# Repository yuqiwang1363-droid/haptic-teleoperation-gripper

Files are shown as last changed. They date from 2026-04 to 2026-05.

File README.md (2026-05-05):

# Haptic Teleoperation Gripper System

## Overview

This project presents a hardware-in-the-loop (HIL) haptic device designed for teleoperation and human-machine interaction. The system consists of a 2-DOF planar linkage for position input and a 1-DOF force-feedback gripper that enables users to perceive virtual object interactions through kinesthetic feedback.

The device captures user motion using encoders and renders force feedback via a DC motor, forming a closed-loop interaction with a virtual environment.

---

## System Architecture

* **Mechanical System**

  * 2-DOF planar linkage for end-effector positioning
  * 1-DOF gripper handle with integrated DC motor for force feedback

* **Sensing**

  * Incremental encoders (Model 3806) for joint angle measurement
  * AS5600 magnetic encoder for absolute gripper angle sensing

* **Embedded System**

  * Arduino-based real-time processing
  * Quadrature decoding and angle computation
  * Motor control for haptic rendering

* **Interface**

  * Serial communication with external simulation (e.g., PyBullet)
  * Enables hardware-in-the-loop interaction

---

## My Contributions

* Designed the **2-DOF linkage mechanism** and **force-feedback handle**
* Performed **component selection** (encoders, motor, sensors)
* Integrated **incremental encoders and AS5600 sensor**
* Developed **Arduino firmware** for sensing and motor control
* Implemented **real-time data acquisition and actuation pipeline**
* Diagnosed and resolved key issues:

  * Encoder drift due to improper mounting
  * Sensor-magnet misalignment
  * Mechanical friction and usability issues
* Optimized gripper geometry and ergonomics for improved user interaction

---

## Hardware

* 2-DOF planar linkage (custom CAD design)
* RS380 DC motor for force feedback
* AS5600 magnetic encoder (I2C)
* Model 3806 incremental encoders (quadrature)
* Bearing-supported rotating handle

See `/hardware` for CAD files, wiring diagrams, and BOM.

---

## Firmware

The Arduino firmware performs:

* Encoder signal decoding (quadrature)
* Angle computation and calibration
* Serial communication
* Motor control for force feedback

Located in:

```bash
/firmware/arduino_main/
```

---

## Control and Modeling

* Forward kinematics for 2R planar linkage
* Real-time position tracking
* Haptic rendering using a virtual wall model
* Force output based on stiffness and penetration depth

See `/control` for details.

---

## Hardware-Software Interface

The system communicates with an external simulation via serial:

**Output (Arduino → Simulation):**

* End-effector position (x, y)
* Gripper angle (α)

**Input (Simulation → Arduino):**

* Contact threshold
* Virtual stiffness

This enables real-time hardware-in-the-loop interaction.

---

## Results

* Stable position tracking after mechanical refinement
* Improved accuracy through proper encoder mounting
* Smooth and responsive force feedback
* Enhanced user interaction through ergonomic design improvements

---

## Project Structure

```bash
hardware/      # CAD, drawings, electronics
firmware/      # Arduino code
experiments/   # testing and observations
docs/          # report and figures
```

---

## Demo
click the picture
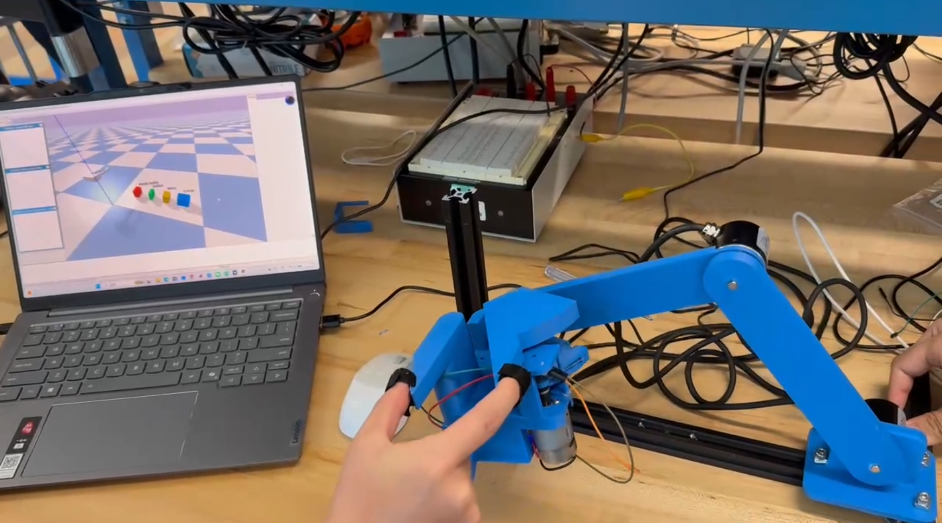
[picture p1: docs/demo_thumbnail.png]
Demo Video (https://www.bilibili.com/video/BV1hrQpB5Ezd)
 

---

## Future Work

* Improve sensing accuracy and calibration
* Reduce mechanical friction and backlash
* Enhance force feedback with advanced control strategies
* Integrate more complex virtual environments

---

## Acknowledgment
This project was conducted at the University of California, San Diego under the supervision of Professor Tania Morimoto.

## 中文说明（Chinese Version）

### 项目简介

本项目设计并实现了一种基于硬件在环（Hardware-in-the-Loop, HIL）的触觉遥操作装置。系统由一个二维平面连杆机构（2-DOF）和一个具有力反馈功能的夹爪手柄（1-DOF）组成，实现了用户动作输入与虚拟环境交互之间的闭环控制。

系统通过编码器采集用户运动信息，并利用直流电机输出力反馈，使用户能够感知虚拟物体的接触与刚度特性，从而提升人机交互的真实感。

---

### 系统结构

* **机械结构**

  * 二自由度平面连杆机构（用于末端位置输入）
  * 一自由度力反馈手柄（集成电机实现夹爪开合与力反馈）

* **传感器系统**

  * 3806 增量式编码器（用于关节角度测量）
  * AS5600 磁编码器（用于夹爪绝对角度测量）

* **嵌入式系统**

  * 基于 Arduino 的实时数据采集与控制
  * 编码器信号正交解码与角度计算
  * 电机驱动与力反馈控制

* **系统接口**

  * 通过串口与外部仿真环境（如 PyBullet）通信
  * 支持硬件在环（HIL）实时交互

---

### 本人工作内容

* 主导 **2自由度连杆机构与力反馈手柄的机械设计**
* 完成 **关键元件选型**（编码器、电机、传感器等）
* 实现 **增量式编码器与AS5600磁编码器的集成**
* 开发 **Arduino嵌入式程序**，实现数据采集与力反馈控制
* 搭建 **完整硬件系统并完成系统级集成**
* 解决关键工程问题：

  * 编码器安装不牢导致的测量误差问题
  * AS5600 磁铁与传感器对齐问题
  * 机械摩擦与结构稳定性问题
* 优化夹爪结构与人机交互设计，提高操作稳定性与触觉感知效果

---

### 硬件系统

* 2自由度平面连杆机构（自定义CAD设计）
* RS380 直流电机（用于力反馈）
* AS5600 磁编码器（I2C通信）
* 3806 增量式编码器（正交输出）
* 轴承支撑的旋转手柄结构

详细硬件设计（包括CAD模型、接线图与物料清单）详见 `/hardware` 目录。

---

### 嵌入式程序

Arduino程序实现以下功能：

* 编码器信号解码（正交解码）
* 角度计算与零位标定
* 串口通信（与上位机/仿真环境交互）
* 电机驱动与力反馈控制

程序代码详见 `/firmware/arduino_main/` 目录。

---

### 控制与建模

* 基于平面2R机构的正运动学进行末端位置计算
* 实现实时位置跟踪与数据映射
* 基于虚拟墙模型（Virtual Wall）实现力反馈
* 根据接触阈值与刚度参数输出反馈力

相关建模与控制细节详见 `/control` 目录。

---

### 硬件-软件接口

系统通过串口实现与外部仿真环境的数据交互：

**输出（Arduino → 仿真）：**

* 末端位置 (x, y)
* 夹爪角度 (α)

**输入（仿真 → Arduino）：**

* 接触阈值（contact threshold）
* 虚拟刚度参数（stiffness）

该机制实现了物理设备与虚拟环境之间的闭环交互（Hardware-in-the-Loop）。

---

### 实验结果

* 通过机械结构优化，实现稳定的位置跟踪
* 编码器固定后显著降低零点漂移与测量误差
* 力反馈输出平滑且响应稳定
* 结构优化后显著提升用户操作体验与交互自然性

实验数据与调试记录详见 `/experiments` 目录。

---

### 项目结构

```bash
hardware/      # 机械设计、CAD模型与电路连接
firmware/      # Arduino嵌入式控制代码
experiments/   # 测试记录、标定与调试过程
docs/          # 报告、图片与说明文档
```

---

### 演示

点击照片
Demo Video (https://www.bilibili.com/video/BV1hrQpB5Ezd) 

---

### 后续工作

* 提升传感器精度与系统标定方法
* 降低机械摩擦与间隙误差（backlash）
* 优化力反馈控制算法（如更高阶控制策略）
* 扩展更复杂的虚拟交互环境

---

### 致谢

本项目在加州大学圣地亚哥分校完成，感谢 Tania Morimoto 教授的指导与支持。

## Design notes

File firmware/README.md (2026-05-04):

# Firmware / 固件

---

## Overview / 项目简介

This firmware runs on an Arduino microcontroller and implements real-time sensing, communication, and force-feedback control for the haptic device.

The system reads joint motion from incremental encoders, measures gripper rotation using an AS5600 magnetic sensor, and communicates with an external system via serial. Based on incoming commands, it drives a DC motor to render haptic feedback.

本固件运行在 Arduino 微控制器上，实现触觉设备的实时数据采集、通信以及力反馈控制。

系统通过读取连杆上的增量式编码器获取关节运动信息，通过 AS5600 磁编码器测量夹爪角度，并通过串口与外部系统（如仿真环境）通信，根据接收到的控制指令驱动电机输出力反馈。

---

## Architecture / 系统架构

Although implemented in a single `.ino` file, the firmware is logically organized into several functional modules:

尽管代码目前以单个 `.ino` 文件实现，但在逻辑上可划分为以下模块：

* **Sensing（传感层）**

  * Read joint angles from incremental encoders
  * Read gripper angle from AS5600 (I2C)

* **State Processing（状态处理）**

  * Convert encoder counts to angles
  * Maintain system state (joint angles + gripper angle)

* **Communication（通信模块）**

  * Send real-time data via serial
  * Receive control parameters from host

* **Control（控制模块）**

  * Compute force feedback command
  * Drive DC motor using PWM

---

## Main Loop / 主循环结构

The firmware follows a structured loop:

固件采用结构化循环：

```cpp
void loop() {
    readEncoders();
    readGripper();
    computeState();
    sendData();
    receiveCommand();
    controlMotor();
}
```

This structure separates sensing, processing, communication, and actuation.

该结构实现了传感、处理、通信与控制的分层设计。

---

## Hardware Interface / 硬件接口

### Incremental Encoders (Model 3806) / 增量式编码器

* Quadrature signals (A/B channels)
* Used for joint angle measurement
* High-resolution relative motion tracking

用于关节角度测量，通过A/B相实现高分辨率位置跟踪。

---

### AS5600 Magnetic Encoder / 磁编码器

* I2C communication (SDA, SCL)
* Absolute angle measurement (0–360°)

用于夹爪角度测量，提供绝对角度信息。

---

### Motor Driver / 电机驱动

* PWM output for torque control
* Direction controlled via digital pins

通过PWM控制输出力矩，实现力反馈。

---

## Serial Communication / 串口通信

### Output (Arduino → Host) / 输出

```text
< x, y, alpha >
```

* `x, y`: end-effector position
* `alpha`: gripper angle

---

### Input (Host → Arduino) / 输入

* Contact threshold
* Stiffness parameter

用于计算力反馈控制信号。

---

## Control Logic / 控制逻辑

Force feedback is implemented using a simple virtual wall model:

系统采用虚拟墙模型实现力反馈：

```cpp
float error = contact_angle - alpha;
float torque = k * error;
```

The torque is converted into a PWM signal to drive the motor.

根据误差计算力矩，并转换为PWM信号驱动电机。

---

## Key Engineering Issues / 关键工程问题

### Encoder Drift / 编码器漂移

* Issue: system failed to return to zero
* Cause: loose encoder mounting
* Fix: rigid mounting using screws

---

### AS5600 Alignment / 传感器对齐

* Issue: unstable angle readings
* Cause: magnet misalignment
* Fix: adjust alignment and maintain 1–3 mm gap

---

### Real-Time Performance / 实时性

* Continuous loop ensures real-time response
* Serial communication optimized to avoid blocking

---

## File Location / 文件位置

```bash
arduino_main/arduino_main.ino
```

---

## Future Work / 后续优化

* Refactor into modular `.h/.cpp` structure
* Implement interrupt-based encoder decoding
* Improve control strategy (e.g., impedance control)
* Add filtering for noise reduction

后续可优化为模块化结构，并引入更高级控制与滤波方法。

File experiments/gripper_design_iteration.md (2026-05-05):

# Gripper Design Iteration

---

## Overview

During early testing, the gripper design was found to limit the user's ability to perceive object size and perform stable manipulation.

This led to a redesign of the gripper geometry to improve tactile interaction and usability.

---

## Problem Description

* Users could not fully close their fingers when interacting with the gripper
* The distance between the two contact surfaces was too large
* Tactile perception of object size was poor
* Interaction felt unnatural and imprecise

This indicated that the initial design did not adequately consider human ergonomics.

---

## Root Cause Analysis

The issue was primarily caused by the geometry of the gripper:

* The front section of the gripper was too thick
* The contact region between the user's fingers and the gripper was too far apart
* The design prioritized structural simplicity over user interaction

As a result, users were unable to achieve natural pinch-like interaction.

---

## Design Modification

To address these issues, the gripper geometry was redesigned:

* The front section of the gripper was tapered (reduced thickness)
* The contact region was brought closer to allow better finger closure
* The shape was adjusted to improve ergonomic compatibility

---

## Results

After redesign:

* Users could comfortably close their fingers around the gripper
* Tactile perception of object size was significantly improved
* Interaction became more natural and controllable

---

## Engineering Insight

This iteration demonstrates that:

> Mechanical design must consider not only structural integrity, but also human interaction.

Even small geometric changes can significantly affect usability and perception.

---

---

# 夹爪结构优化

---

## 概述

在初期测试中发现，夹爪结构设计限制了用户对物体尺寸的感知能力，同时操作稳定性较差。

因此对夹爪结构进行了优化，以提升触觉交互效果与使用体验。

---

## 问题描述

* 用户无法完全闭合手指进行操作
* 两个接触面之间距离过大
* 对物体尺寸的感知能力较差
* 操作过程不自然，控制精度低

说明初始设计未充分考虑人机交互需求。

---

## 原因分析

问题主要来源于夹爪的几何结构：

* 前端结构过厚
* 手指接触区域间距较大
* 设计更偏向结构实现，而非操作体验

导致用户无法实现自然的“捏合”动作。

---

## 结构改进

针对该问题进行了如下优化：

* 对夹爪前端进行斜向减薄（tapered design）
* 缩小接触区域之间的距离
* 调整整体形状以提升人体工学适配性

---

## 改进效果

优化后：

* 用户可以自然闭合手指进行操作
* 对物体尺寸的感知明显提升
* 操作更加稳定、自然

---

## 工程启示

该改进表明：

> 机械设计不仅要满足结构需求，还需要考虑人机交互体验。

细微的结构变化也可能对系统性能产生显著影响。

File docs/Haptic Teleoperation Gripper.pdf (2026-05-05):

Abstract — Existing virtual teleoperation systems often lack adequate haptic feedback, creating a "transparency gap" that diminishes the physical realism of human demonstrations. To address this, we present a low-cost, high-fidelity haptic teleoperation gripper based on an impedance-type Hardware-in-
the-Loop | (HIL) | architecture. | The | system | seamlessly
synchronizes physical kinesthetic inputs with a PyBullet physics engine in real-time. By employing a dynamic unilateral virtual wall model, the system calculates spatial contact thresholds and modulates virtual stiffness to actuate a DC motor, generating proportional resistive torque. This allows operators to accurately perceive both the geometric size and material compliance of virtual objects. Supported by optimized signal filtering to eliminate mechanical jitter, the interface provides stable bidirectional force feedback, demonstrating significant potential for generating physically consistent data for Sim-to-Real manipulation tasks.

Keywords: Haptic Feedback, Teleoperation, Hardware-inthe-Loop, Impedance Control, Virtual Environment

I. INTRODUCTION
The | development | of | high-performance | robotic
manipulation policies increasingly relies on large-scale, high-quality demonstration datasets, especially within the Sim-to-Real paradigm. However, traditional data collection through physical robotic systems is often constrained by high hardware costs, maintenance requirements, and limited scalability. As a result, virtual environments have emerged as a promising alternative for scalable data generation. Nevertheless, existing virtual teleoperation systems frequently lack sufficient haptic feedback, leading to a significant “transparency gap” between user actions and perceived interaction forces.

In particular, when operators manipulate virtual objects without force feedback, they are unable to accurately perceive contact events or object properties such as stiffness and rigidity. This limitation often results in unrealistic demonstrations, reducing the effectiveness of collected data for training robotic policies. To address this issue, it is essential to design interfaces that provide synchronized kinesthetic feedback, enabling users to experience physically consistent interactions within simulated environments.

In this project, we present a wearable kinesthetic feedback interface designed for teleoperation of a robotic gripper in a virtual environment. The system establishes a bidirectional interaction loop: user finger motions are captured through

*Research supported by ABC Foundation.
F. A. Author is with the National Institute of Standards and Technology, Boulder, CO 80305 USA (corresponding author to provide phone: 303-555-5555; fax: 303-555-5555; e-mail: author@ boulder.nist.gov).

high-precision angle sensing and mapped to a virtual gripper, while a motorized actuation mechanism generates reverse torque proportional to simulated interaction forces. This active resistance allows users to perceive contact and grasp forces in real time, thereby improving the realism and fidelity of teleoperation.

Our design focuses on accessibility, scalability, and usability. By employing a lightweight wearable structure and a simplified two-finger interaction paradigm, the system lowers the barrier to large-scale demonstration data collection. Additionally, the integration of force feedback enhances human-in-the-loop control, making the interface suitable for generating high-quality training data for robotic learning systems.

II. BACKGROUND

Recent advances in teleoperation and haptic feedback systems have demonstrated the importance of combining motion capture with force feedback to achieve realistic and effective human–robot interaction. Vision-based teleoperation frameworks such as DexPilot [1] enable high-fidelity retargeting of human hand motions to robotic manipulators, significantly improving task performance and providing valuable demonstration data. However, these systems primarily focus on motion mapping and lack sufficient haptic feedback, limiting the operator’s ability to perceive interaction forces.

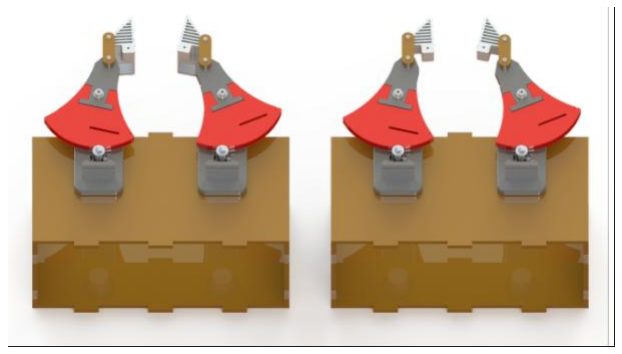
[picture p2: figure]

Figure 1 Teleoperated Two-Finger Gripper [5]

To address this limitation, various wearable haptic devices have been developed to provide kinesthetic feedback. Peng et al. [2] introduced a lightweight exoskeleton glove that employs mechanical linkages and impedance control to render grasping resistance, improving perceived realism and safety.

S. B. Author, Jr., was with Rice University, Houston, TX 77005 USA. He is now with the Department of Physics, Colorado State University, Fort Collins, CO 80523 USA (e-mail: author@lamar. colostate.edu).
T. C. Author is with the Electrical Engineering Department, University of Colorado, Boulder, CO 80309 USA, on leave from the National Research Institute for Metals, Tsukuba, Japan (e-mail: author@nrim.go.jp).

## Haptic Teleoperation Gripper

Yukang Hu, Dongjun Tan, Yuqi Wang University of California, San Diego

Similarly, Wang et al. [3] proposed a modular glove integrating triboelectric sensing with pneumatic actuation, enabling simultaneous cutaneous and kinesthetic feedback. These works highlight the importance of combining sensing and actuation to achieve closed-loop interaction in teleoperation systems.

In addition to active force-feedback devices, passive force rendering approaches have also been explored. Cassar and Saliba [4] developed a glove based on magnetorheological fluid (MRF), which modulates resistance through controllable damping rather than active actuation. Such passive systems offer inherent safety advantages while still providing perceptual cues about object properties. However, they may lack the dynamic range and responsiveness required for complex interaction scenarios.

Furthermore, prior studies on teleoperated grippers have demonstrated that even simple pinch-based interfaces can effectively convey material properties such as hardness and softness. The work in [5] shows that combining grasp sensing with force feedback enables users to distinguish between different object stiffness levels, supporting more realistic manipulation and interaction, as shown in Figure 1.

Building upon these prior works, our system focuses on a compact, wearable, and actively actuated interface that integrates motion sensing and torque-based force feedback within a virtual environment. By leveraging a simplified two-finger gripper paradigm and real-time force rendering, the proposed approach aims to balance system complexity, usability, and scalability for data-driven robotic learning applications.

III. HARDWARE DESIGN

A. Mechanical Design
The mechanical structure of the system is illustrated in Figure 1. The device consists of a 2-degree-of-freedom (2-DOF) planar linkage mechanism combined with a 1-degreeof-freedom (1-DOF) rotating handle located at the end effector. The full structure can be seen in Figure 2.

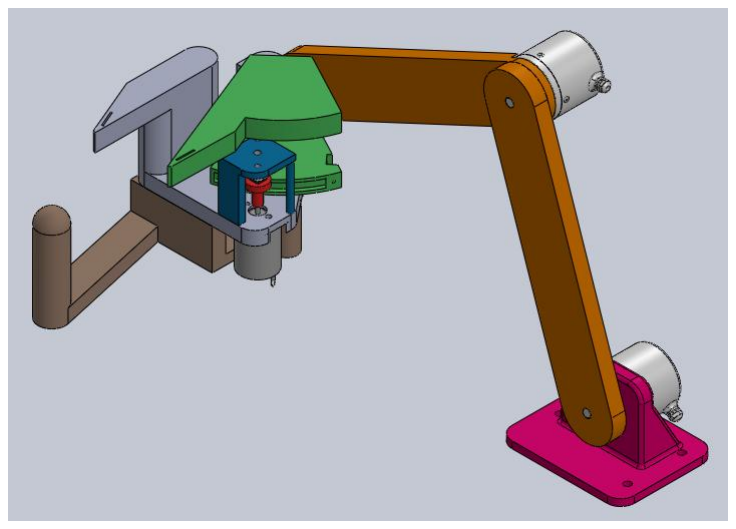
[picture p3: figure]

Figure 2 CAD model of the haptic device

The dual-linkage mechanism is responsible for enabling the planar motion of the end effector and is equipped with passive rotary joints for position sensing. This configuration allows the user to freely maneuver the handle within a two-dimensional workspace. The end-effector position is determined through forward kinematics based on the measured joint angles.

At the end effector, an additional rotational degree of freedom is introduced via a bearing-supported handle. This handle is mechanically decoupled from the linkage mechanism, allowing it to rotate independently without affecting the movement of the joints.

A DC motor is integrated within the handle to provide force feedback capabilities. A bearing connection is employed between the linkage mechanism and the handle to ensure smooth rotation while minimizing the transmission of unwanted torque to the joints.

This decoupled design enhances the human-machine interaction experience by enabling natural hand movements, while simultaneously facilitating precise position sensing through the linkage mechanism. The entire structure is designed to minimize friction and ensure the stable operation of the system.

B. Hardware Component
Regarding the hardware aspects of this system, the design incorporates passive joint sensing as well as active force feedback at the end-effector.

Two Model 3806 incremental encoders are responsible for measuring joint positions; these encoders offer high resolution for capturing relative angular data. Testing has demonstrated that they are highly suitable for tracking a user's continuous movements. Furthermore, their compact design makes them particularly convenient for mounting directly onto moving joints. As shown in Figure 3.

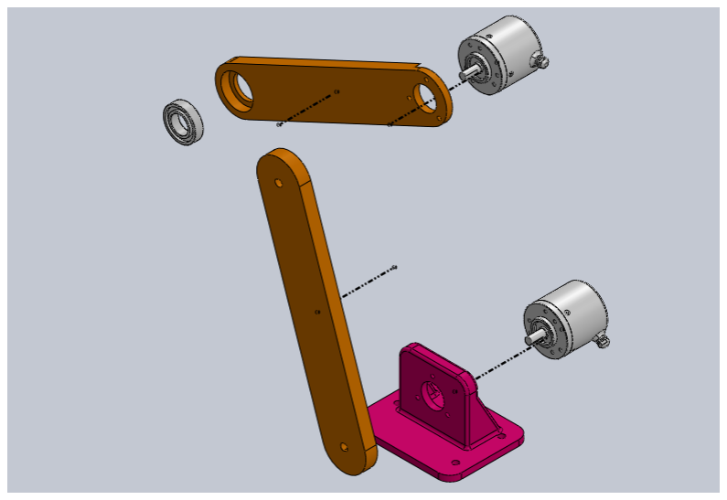
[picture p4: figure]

Figure 3 Exploded view of the linkage assembly

In the force-feedback gripper section, an AS5600 magnetic encoder is positioned atop the motor, oriented perpendicularly to the axis of rotation. As the motor rotates, a magnet mounted at the front end of the motor shaft rotates in tandem, enabling the encoder to accurately capture the motor's rotational motion. This precise monitoring ensures a stable output for the force-feedback control mechanism.

The force-feedback functionality is further realized through an RS380 DC motor mounted within the handle assembly. This motor features a compact form factor and delivers greater torque output capabilities compared to the

RS370 model utilized in the Hapkit curriculum. This design ensures effective haptic interaction while simultaneously reducing the mechanical complexity of the overall system.As shown in Figure 4.

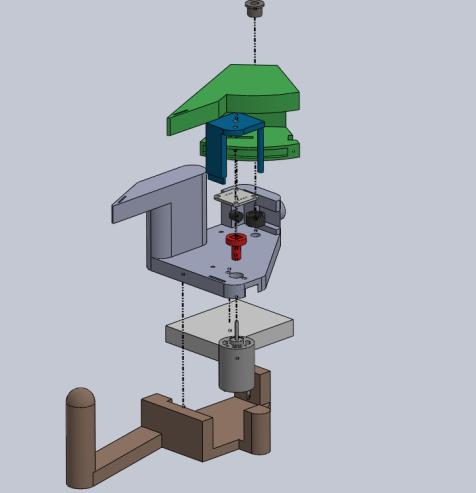
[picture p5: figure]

Figure 4 Exploded view of the end-effector handle assembly

C. Sensor Integration
The system integrates both incremental and absolute sensor technologies to ensure that information is captured in the most appropriate manner.

For the two degrees of freedom, a Model 3806 incremental encoder is installed at each joint of the linkage mechanism to measure angular displacement. Since these encoders measure changes in position rather than absolute values, the linkage must be manually set to a "zero" position, serving as the initial reference point, whenever the system is powered on.

Each encoder generates two digital signals (channels A and
B) with a 90∘phase difference, enabling both angular position tracking and rotation direction detection.

To decode the quadrature signals, a state-based lookup table is employed. At each sampling step, the current and previous states of the encoder signals are combined to form a 4-bit index, which is used to determine the incremental count update. This approach allows robust detection of valid transitions while rejecting invalid state changes due to noise.

The accumulated encoder counts are then converted into joint angles using

θ =

(c+coffset)
CPR | ⋅ 2π | (1)

where c is the accumulated count, coffset is a calibration offset corresponding to the initial configuration, and CPR denotes the counts per revolution. In our implementation, CPR is set to 2400, accounting for quadrature decoding (i.e., four counts per encoder pulse).

Additionally, a sign inversion is applied to one joint to ensure consistency with the kinematic convention of the planar 2R manipulator. Dynamics can be seen in Figure The measured joint angles are subsequently used in forward kinematics to compute the end-effector position:

x = L1 cos θ1 + L2 cos(θ1 + θ2

) | (2)

y = L1 sin θ1 + L2 sin(θ1 +θ2

) | (3)

where L1and L2 are the link lengths.

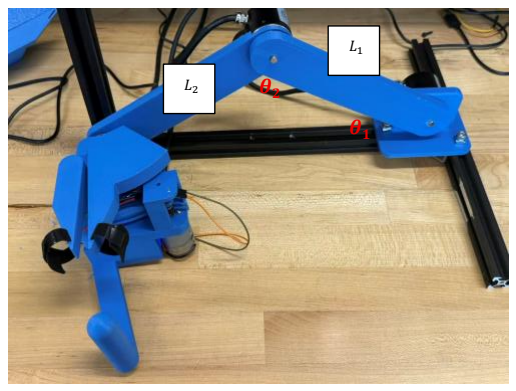
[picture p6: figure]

Figure 5 Arm Dynamics

Compared to absolute magnetic encoders, incremental encoders offer higher update rates and lower latency, making them suitable for continuous motion tracking of the linkage. However, they require initialization and are subject to cumulative drift if counts are lost. Therefore, in this system, incremental encoders are used for high-frequency joint tracking, while the absolute magnetic sensor (AS5600) is used for reliable measurement of the gripper state.

At the force-feedback handle, an AS5600 magnetic encoder is employed. This encoder provides absolute angular measurement data, thereby ensuring stable and consistent force feedback.

To measure the gripper aperture angle, a contactless magnetic rotary encoder (AS5600) is employed. The AS5600 operates based on Hall-effect sensing, where an internal array of Hall sensors detects the orientation of a diametrically magnetized permanent magnet mounted on the rotating shaft. By estimating the angular position of the magnetic field vector, the sensor provides an absolute angular measurement over a full 0

∘

to 360∘
range.

The device outputs a 12-bit digital value (0–4095), corresponding to one full revolution. The measured angle is obtained by linearly mapping the raw sensor reading to the angular domain as

θ =

N
4096 ⋅ 360∘
(4)

where Ndenotes the raw encoder value. In implementation, the sensor is accessed via the I

2C interface by reading two consecutive registers (high and low bytes), which are combined and masked to obtain the 12-bit angle measurement.

Compared to incremental encoders used for joint position sensing, the AS5600 provides absolute angle measurements without requiring initialization or homing. This property makes it particularly suitable for measuring the gripper aperture, where reliable and drift-free position sensing is essential despite cable transmission compliance or mechanical backlash.

Precise alignment between the sensors and their corresponding rotating components is critical to achieving accurate measurements. Specifically, the air gap between the AS5600 sensor and its magnet must be maintained within the recommended range of 1 to 3 millimeters. The incremental encoders, conversely, are rigidly mounted to prevent misalignment and ensure reliable signal output.

By precisely capturing the motion of every joint using these two distinct sensor technologies, the system ensures the overall robustness of the haptic interaction experience.

IV. SOFTWARE DESIGN

A. Position Mapping
The software system establishes a real-time mapping between the physical haptic device and the virtual gripper in the PyBullet environment. The Arduino continuously transmits three values through serial communication: the planar end-effector position (x, y) in centimeters and the gripper handle angle αin degrees. These measurements are parsed by the Python simulation program and converted into the pose command of a WSG50 gripper model.

Since the physical device is designed for planar motion, only two translational degrees of freedom are mapped into the virtual workspace. Specifically, the measured horizontal displacement is mapped to the PyBullet X-axis, while the measured vertical displacement of the physical linkage is mapped to the PyBullet Z-axis. The virtual gripper remains at a fixed Y-position so that the interaction is constrained to a two-dimensional manipulation plane. The mapping is defined as
Xv = kx x | (5)
Zv = kz y +Zoff | (6)
Yv = 0 | (7)

where xand yare the measured end-effector coordinates from the hardware in centimeters, Xv

, Yv | , and Zv denote the
virtual gripper position in meters, kx and kz are workspace scaling coefficients, and Zoffis a constant height offset used to keep the gripper above the virtual ground plane. In the current implementation, kx = 15/100 , kz = 5/100 , and Zoff = 0.05m. This anisotropic scaling was selected empirically to produce a comfortable and visually clear workspace in simulation.

To ensure consistent grasping orientation, the gripper base frame is initialized with a fixed rotation so that the finger closing direction aligns with the virtual Y-axis. As a result, the user perceives grasping as occurring orthogonally to the planar motion of the end effector, which matches the intended interaction design.

The handle angle measured by the AS5600 sensor is used to control the opening of the virtual gripper. The sensor output is interpreted in the range 0

∘

to 360∘
, where 0

∘
| corresponds to
the fully closed state and 360∘
corresponds to the fully open state. First, the angle is normalized into an opening ratio:

r =

α −αmin αmax − αmin | (8)

where αmin = 0

∘

and αmax = 360∘
. The ratio is then
clipped to the interval [0,1] and mapped to the prismatic finger joint target of the WSG50 gripper model:
qf = qclosed + r(qopen−qclosed) | (9)

where qf is the commanded finger joint position, and qclosedand qopendenote the joint coordinates associated with the fully closed and fully open states, respectively. This linear interpolation ensures a continuous and intuitive relationship between user finger motion and virtual gripper aperture.

In addition, the mapped vertical position is constrained to remain above the ground plane in simulation, preventing the virtual gripper from penetrating the table surface. Through this position-mapping pipeline, the system creates a direct and stable correspondence between physical motion and virtual manipulation, enabling real-time teleoperation of the gripper within the simulated environment.

B. Gripper control

The gripper control module converts the user’s measured handle angle into the opening motion of the virtual WSG50 gripper and manages stable grasp execution during object interaction. In the implemented system, the AS5600 magnetic angle sensor provides the gripper command αin the range of 0

∘

to 360∘
, where 0

∘ denotes the fully closed state and 360∘denotes the fully open state. This angle is first normalized into an opening ratio

r =

α − αmin

αmax − αmin

, | (10)

where αmin = 0

∘

and αmax = 360∘
. The normalized ratio is
then clipped to [0,1] and mapped to the prismatic finger joint target of the WSG50 model:
qf = qclosed + r(qopen−qclosed), | (11)
where qfis the commanded finger position, and qclosedand qopenrepresent the joint coordinates corresponding to the fully closed and fully open states, respectively. This mapping provides an intuitive one-to-one correspondence between the user’s pinch motion and the virtual gripper aperture.

To drive the virtual gripper, each finger joint is controlled using PyBullet position control. For each simulation cycle, the desired finger position is updated according to the measured angle and sent to the gripper joints as a position command. In free motion, a relatively high motor force is used so that the gripper can respond rapidly to the user input. Once an object has been grasped, the holding force is reduced to maintain stable contact while avoiding excessive squeezing. This control strategy allows the gripper to remain responsive during approach and compliant during object retention.

To improve grasp robustness, a grasp-assist mechanism is introduced. When the gripper closes beyond a predefined threshold and valid contacts are detected on both sides of a candidate object, the object is attached to the gripper through a pose-following update in the simulation. At this stage, the system computes a safe closing target based on the object size along the grasp axis:
gsafe = gobj + gclr, | (12)
where gobjis the estimated object span along the gripper closing direction and gclr is a small clearance margin. The corresponding finger joint position is then limited so that the gripper cannot continue closing beyond the allowable grasp width. In other words, after grasp capture, the user is still allowed to open the gripper for release, but additional closing motion is blocked to preserve a stable grasp configuration.

The release logic is similarly threshold-based. When the user reopens the gripper above a predefined release angle, the grasp-assist state is disabled, and the object is returned to normal free-body dynamics. This mechanism ensures that the transition between free motion, grasp acquisition, and object release remains stable and predictable in real time.

In addition to finger motion control, the gripper control module also supports object-dependent force-feedback rendering through a virtual-wall mechanism. Once a potential contact state is detected, the simulation computes a contact angle corresponding to the maximum allowable gripper closure for the current object. If the user attempts to close the gripper beyond this angle, the contact angle is transmitted back to the Arduino controller, which renders local kinesthetic resistance on the physical handle. As a result, the virtual gripper control and the physical haptic feedback remain synchronized, enabling the user to perceive object contact and stiffness while manipulating the simulated environment.

C. Virtual Environment

The virtual environment is implemented in PyBullet to provide a real-time physics-based simulation for hardware-inthe-loop teleoperation. Its primary role is to maintain a synchronized digital representation of the gripper state, evaluate contact conditions during manipulation, and generate the simulation-side variables required for haptic feedback rendering. The environment runs as a continuous control loop in which the physics engine is updated at a fixed time step while sensor data from the hardware device are received
asynchronously | through | serial | communication. | This
architecture enables stable bidirectional coupling between the physical interface and the simulated task.

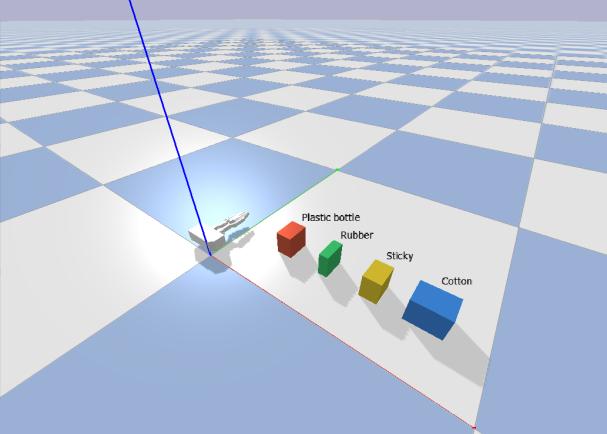
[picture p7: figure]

Figure 6 Virtual Environment

To improve robustness, the software separates serial communication from the physics update loop using a background thread. The serial thread continuously parses the incoming measurements and updates shared state variables, while the main simulation loop reads the latest available values and applies them to the virtual system. This decoupled design reduces blocking delays caused by communication latency and helps maintain consistent simulation timing. In addition, low-level filtering and signal clipping are used to suppress measurement noise and keep the gripper command within a valid operating range.

The environment also includes a parametric object model that supports different virtual material behaviors through adjustable stiffness-related parameters. Rather than treating all grasp targets identically, the simulation assigns each object a distinct set of contact-response coefficients, allowing the same teleoperation interface to represent materials with different apparent resistance characteristics. This object-dependent parameterization is used by the feedback module to determine when contact occurs and how strongly the physical gripper should resist further closure. In this way, the virtual environment functions not only as a geometric simulator but also as a material-response model for haptic interaction.

To enhance perceptual realism, the simulation further incorporates a visual deformation mechanism. When the virtual gripper compresses an object, the rendered object geometry is modified according to the estimated penetration level and material stiffness. Importantly, this deformation is applied only to the visual representation, while the underlying collision geometry remains unchanged. This separation preserves contact stability in the physics engine while still providing the user with an intuitive visual cue of softness or compression. As a result, the environment can convey differences in object behavior through both haptic resistance and visual appearance without compromising numerical stability.

Overall, | the | virtual | environment | serves | as | the
computational backbone of the system. It integrates real-time communication, physics simulation, contact evaluation, material parameterization, and visual feedback into a unified framework, thereby enabling stable and responsive teleoperation experiments with closed-loop kinesthetic interaction.
V. METHODS
A. Impedance-type Hardware-in-the-Loop Interaction

This project employs an impedance control paradigm to achieve high-fidelity interaction between the user and the virtual simulation environment. Unlike traditional open-loop teleoperation, this system constructs a bidirectional hardware-in-the-loop (HIL) closed-loop architecture. The physical gripper functions as an impedance-type haptic interface, utilizing a magnetic encoder to capture the user's kinematic input (i.e., the absolute opening angle of the gripper) in real time. This physical state is synchronously mapped to a virtual WSG50 gripper within the physics engine (PyBullet).

When the virtual gripper intersects with a target object in the simulation space, the physics engine evaluates the collision dynamics in real time and extracts key constraint parameters (such as contact angle and virtual stiffness), which are then transmitted to the underlying hardware. Subsequently, the microcontroller dynamically calculates and outputs the corresponding resistive torque based on the deviation (i.e., penetration depth) between the user's actual physical position and the virtual constraints, thereby closing the haptic rendering loop.

B. Haptic Rendering of Object Size

To enable users to accurately perceive the size differences of virtual objects without visual assistance, the system introduces a dynamic unilateral virtual wall (UVW) mechanical model. In the simulation environment, when the fingertips of the virtual gripper contact the bounding box of an object, the physics engine precisely records the physical gripper's opening angle at that moment, defining it as the contact threshold (θcontact ).

The low-level microcontroller continuously compares the user's real-time angle (θcurrent) with the contact threshold at an exceptionally high frequency (with a control period of approximately 8 ms). Once the user attempts to close the gripper beyond this threshold (i.e., θcurrent < θcontact ), the system registers a "virtual penetration". Because larger objects trigger collisions earlier at a wider gripper aperture, their θcontact is significantly greater than that of smaller objects. This dynamic threshold-based blocking mechanism ensures that when grasping objects of varying sizes, users experience mechanical resistance at different spatial positions, thereby accurately reconstructing the geometric scale of the objects at the kinematic level.

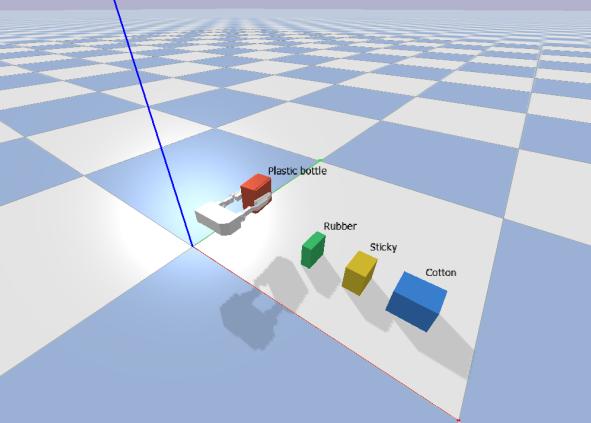
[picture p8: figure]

Figure 7 Gripper Interacting with the Environment

C. Material Perception via Stiffness Modulation

To address the grasping feedback of objects with diverse material properties (e.g., highly deformable soft sponges versus incompressible rigid metal blocks), the system differentiates materials by dynamically modulating the stiffness coefficient (k) of the virtual wall. On the software algorithm side, the system assigns independent mechanical stiffness attributes to each target object (for instance, 300 N/m for soft objects and 5000 N/m for rigid objects). Upon collision, this parameter is transmitted to the low-level motor controller alongside the contact angle.

The hardware end calculates the virtual restoring force resisting the finger pinch based on Hooke's Law. The motor's output torque is directly proportional to the current angular penetration depth and the object's virtual stiffness (k). Through this stiffness modulation strategy, when a user grasps a lowstiffness object, the feedback torque rises gently as the penetration depth increases, allowing the user to continue compressing the physical gripper inward, thereby simulating the elastic deformation of flexible materials perfectly. Conversely, when grasping a high-stiffness object, even a microscopic angular violation triggers a sharply amplified PWM current output, driving the motor to instantaneously generate a peak stall torque, thereby providing an insurmountable illusion of rigidity. This hardware-software synergistic mechanism successfully endows the physical gripper with the capability to distinguish multidimensional material properties.

VI. RESULTS
To assess the perceptual quality of the system, we collected user responses through a short questionnaire consisting of four evaluation items. Each question was designed to measure a different aspect of the teleoperation experience. The matrices can be seen in Table 1 Response from users. The first question evaluated whether users could distinguish between different categories of virtual objects, reflecting the overall discriminability of object-level interaction cues. The second question focused specifically on stiffness perception, examining whether the haptic feedback allowed users to identify differences in material compliance across objects. The third question assessed shape perception, that is, whether users could sense geometric differences among the grasped objects through interaction. Finally, the fourth question evaluated the quality of motion rendering in the virtual environment, indicating how well the simulated gripper motion matched the user’s physical input and whether the system felt responsive and natural during operation.
Table 1 Response from users
Questions | Average Scores | Meaning
Can you tell the difference between different type of objects? | 4.33 | Ability to distinguish object categories
Can you tell the different stiffness between the objects? | 4.33 | Perceived difference in object stiffness
Can you feel the different shape of the objects? | 3.83 | Ability to perceive object shape variation
Does the virtual environment rendering the movement well? | 4.83 | Quality of motion rendering and system responsiveness

VII. DISCUSSION
A. Mechanical Design and Hardware Deployment

Through an iterative design optimization process, we identified and resolved several challenges related to both mechanical design and hardware deployment. Position tracking errors were primarily attributed to the improper mounting of the incremental encoder. When the encoder was not securely fixed, minute relative displacements between the encoder and its mount resulted in significant measurement errors. This issue was ultimately resolved by firmly fastening the encoder with screws, thereby restoring consistent system behavior at the zero-point position. In addition, during the deployment of the angle sensor, we found that the alignment between the sensor and the magnet was critical. If the AS5600 sensor and the magnet were not placed along the same axis, the measured angle exhibited noticeable errors, which further reduced the accuracy of force-feedback rendering.

To enhance the user experience, we introduced a vertical handle design. Compared to the initially adopted pinch-grip operation method, this handle provides a more robust and ergonomically sound mode of human-machine interaction, enabling users to achieve greater precision in manipulation. Furthermore, we discovered that the thickness of the gripper was a critical factor limiting tactile perception. In the initial design, the gripper structure impeded the full closure of the user's fingers, thereby diminishing sensitivity to object size. To address this issue, we thinned the gripper tips, which improved tactile feedback during grasping.

Additionally, we incorporated mounting holes into the front section of the gripper structure to facilitate cable-tie installation. These improvements not only enhanced force transmission efficiency but also provided a convenient mechanism for controlling the opening and closing actions of the gripper. Finally, from a hardware integration perspective, it would be preferable to use encoders that provide absolute position measurements. This would eliminate the need to manually reset the mechanism to a zero position every time the program restarts, thereby improving usability and deployment efficiency. Overall, these improvements demonstrate the critical importance of precise mechanical design and reliable sensor integration in achieving accurate perception and effective haptic interaction.

B. Virtual Environment and Software Design

Initially, the system exhibited anomalous behavior where the physical gripper's rendered angle would abruptly reset to zero upon exceeding 180 degrees. Analysis revealed that the original calibration logic constrained the angle difference within a [-180°, 180°] domain. Consequently, angles exceeding 180 degrees were interpreted as negative wraparounds, which subsequently triggered the system's deadband clamp, nullifying the data. This limitation was resolved by redesigning the mapping algorithm to project the AS5600 magnetic encoder readings into a strictly continuous [0°, 360°] coordinate space. Combined with a dedicated zero-point offset (CLOSED_OFFSET) and directional scaling, the system achieved seamless and monotonic angle tracking throughout the gripper's full range of motion.

A major challenge involved severe mechanical oscillations and acoustic resonance during static grasping. Root-cause analysis identified two contributing factors across the software and hardware layers. In the software domain, the unconstrained execution rate of the microcontroller's main loop caused the exponential moving average (EMA) low-pass filter to update too rapidly, neutralizing its damping characteristics against serial communication noise. This was mitigated by implementing a strict 8-ms timer-based control loop, restoring the filter's time constant. In the hardware domain, driving the DC motor at the default low PWM frequency (~976 Hz) induced strong electromagnetic resonance and physical vibration. By reassigning the actuation signal to a hardware timer capable of ultrasonic frequency modulation (31.25 kHz), the electromagnetic noise was shifted beyond human perception, yielding highly smooth and silent force rendering.

During early force-feedback testing, the actuator generated an erroneous "pulling" (closing) force instead of the expected resistive (opening) force upon virtual contact. Initial attempts to invert the software directional flags proved ineffective due to an incomplete H-bridge configuration. The generic motor driver was operating with only one active directional pin, meaning reversing the signal resulted in passive braking rather than active reverse torque. This was rectified by expanding the low-level control architecture to actively drive both directional input pins (IN1 and IN2) of the motor driver. This modification unlocked true bidirectional torque modulation, allowing the unilateral virtual wall to correctly exert resistive forces against the user's grip.

Early simulation testing revealed that objects with different visual appearances and masses provided identical haptic feedback. This discrepancy arose because mass in standard rigid-body physics engines (such as PyBullet) dictates inertial properties but does not naturally translate to haptic stiffness. To address this, a dynamic stiffness-mapping architecture was introduced in the Python simulation layer. By assigning distinct virtual spring coefficients (k) to specific object IDs— for instance, 300 N/m for highly deformable objects and 5000 N/m for rigid bodies—the physical hardware was able to dynamically modulate its torque output based on both the penetration depth and the specific material properties. This decoupled approach successfully bridged the gap between rigid-body simulation and deformable haptic perception.

VIII. CONCLUSION

This project presented the design and implementation of a wearable haptic teleoperation system for virtual gripper manipulation. The proposed system integrates a 2-DOF planar linkage for position input, a 1-DOF force-feedback gripper for kinesthetic interaction, incremental encoders for joint sensing, and an AS5600 magnetic angle sensor for gripper aperture measurement. A complete hardware-software pipeline was developed to map user motion into a PyBullet-based virtual environment and to render object-dependent force feedback during grasping.

Experimental results and user evaluation showed that the system can achieve stable position tracking, responsive gripper control, and distinguishable haptic rendering for objects with different stiffness properties. The virtual environment also provided consistent motion rendering and supported intuitive teleoperation. Through iterative refinement of the mechanical structure, sensor deployment, and control implementation, the overall usability and reliability of the system were significantly improved.

Overall, the project demonstrates a practical and low-cost approach for combining real-time teleoperation, virtual interaction, and kinesthetic feedback in a compact haptic interface. Future work will focus on improving sensing accuracy, reducing mechanical friction and backlash, and further enhancing force-feedback fidelity through more advanced control and interaction models.

ACKNOWLEDGMENT
The authors would like to express their sincere gratitude to Professor Morimoto and the teaching assistant, Anoush Sepehri, for their continuous guidance, insightful feedback, and generous support throughout the course of this project. Their assistance was invaluable in the design, implementation, and refinement of the system.

REFERENCES

[1] L. Shao, J. Xu, J. Zhang, and H. Liu, “DexPilot: Vision-Based Teleoperation for Dexterous Robotic Hand-Arm System,” Robotics: Science and Systems (RSS), 2021. Available: https://arxiv.org/abs/2109.09109
[2] S. Peng, M. Yu, X. Geng, X. Cheng, and P. Wang, “A Lightweight Exoskeleton Force-Feedback Glove (EFFG) for Teleoperation,”
Machines, | vol. | 13, | no. | 3, | p. | 199, | 2023. | Available:
https://doi.org/10.3390/machines13030199
[3] R. Wang, L. Jiang, J. Li, Z. Dai, M. Liu, P. Lv, X. Li, and M. Zhu, “Tactile and Kinesthetic Communication Glove with Fusion of Triboelectric Sensing and Pneumatic Actuation,” Nano Energy, vol. 131, part A, p. 110273, 2024. doi: 10.1016/j.nanoen.2024.110273.
[4] D. J. Cassar and M. A. Saliba, “A Force Feedback Glove Based on Magnetorheological Fluid: Preliminary Design Issues,” in Proc. IEEE Mediterranean Electrotechnical Conf. (MELECON), 2010, vol. 3, pp. 618–623. doi: 10.1109/MELCON.2010.5476012.
[5] “Haptic Hardness Detection with Teleoperated Two-Finger Gripper,” 2023. [Online]. Available: https://charm.stanford.edu/ME327/2023-Group6.

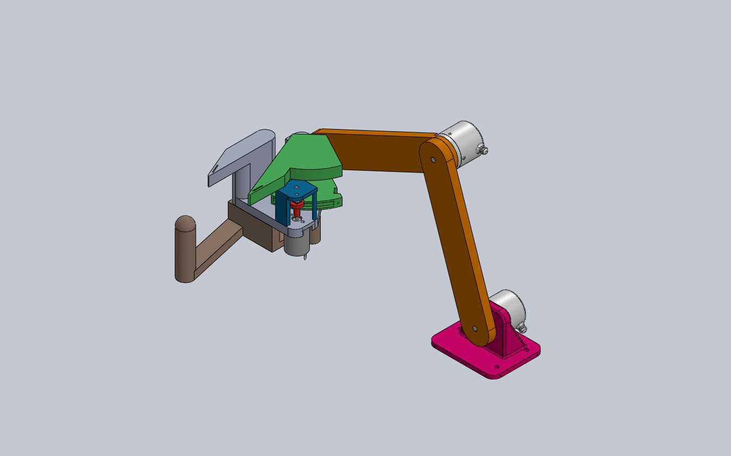
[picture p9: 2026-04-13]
hardware/final.PNG

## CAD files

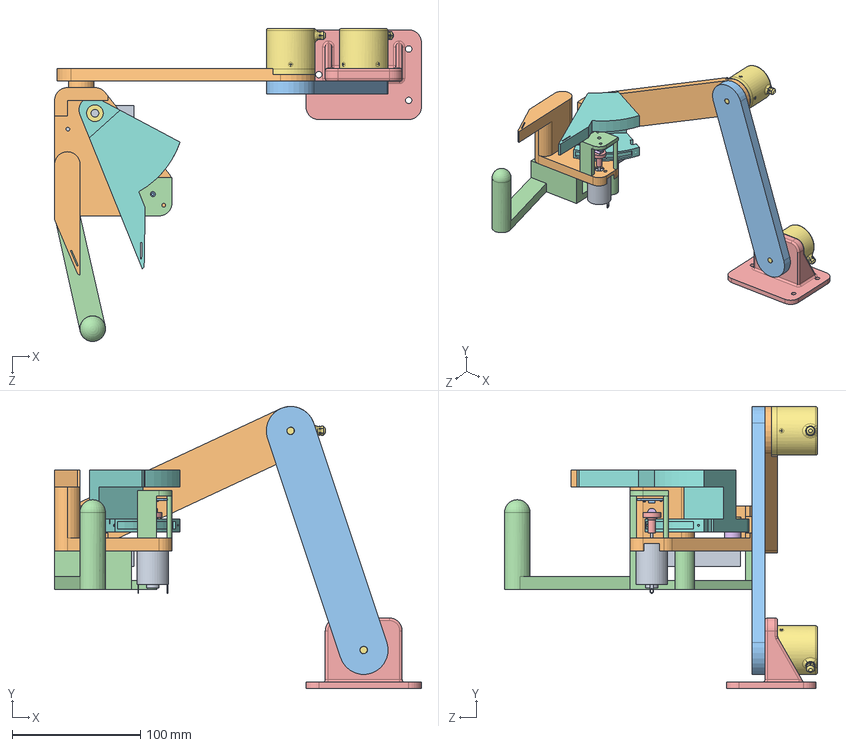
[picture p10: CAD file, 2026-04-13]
hardware/final.SLDASM
285.8 x 219.8 x 243.8 mm
RS-380SH
3basic
AS5600
support
rotationlink
magnet
ESP3806-001系列增量式编码器_ESP3806-001G3600BZ15E x 2
handle
hapkit
link1
link2
moving_handle
root
垫圈
轴套
6902ZZ 15×28×7_深沟球轴承

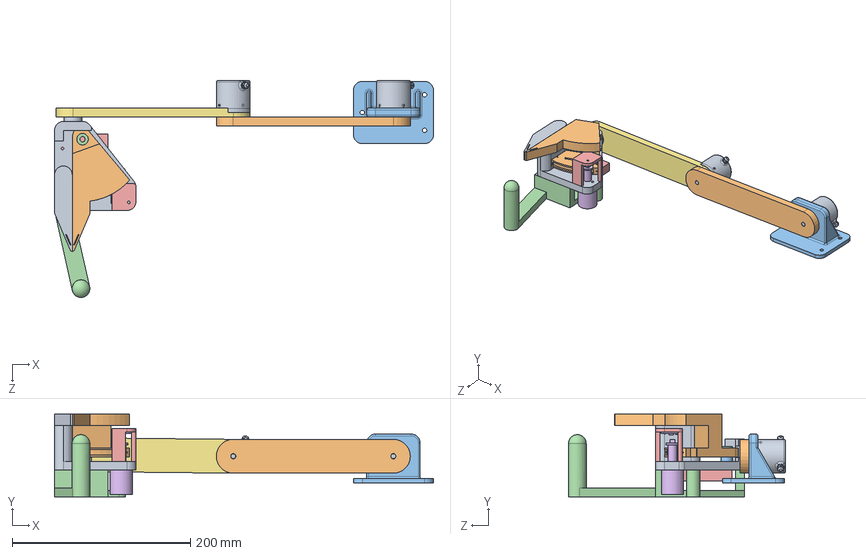
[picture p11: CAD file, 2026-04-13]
hardware/装配体2.SLDASM
425.8 x 93.0 x 243.8 mm
basic
handle
垫圈
轴套
support
motor_handle
link1
6902ZZ 15×28×7_深沟球轴承
ESP3806-001系列增量式编码器_ESP3806-001G3600BZ15E x 2
link2
root
moving_handle
hapkit
AS5600

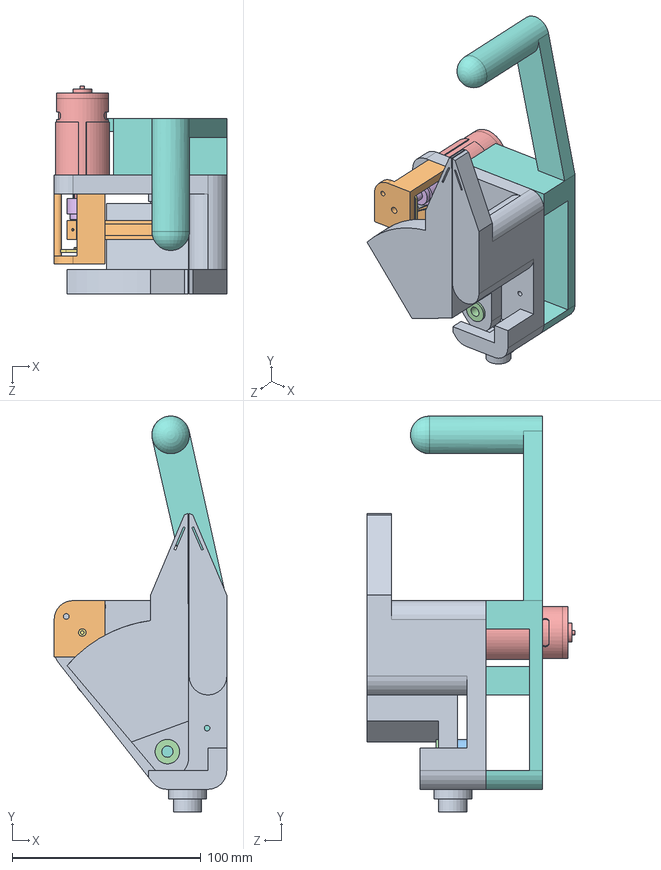
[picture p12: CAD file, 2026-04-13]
hardware/装配体4.SLDASM
91.5 x 209.8 x 110.2 mm
2basic
support
垫圈
轴套
RS-390-6V DC motor
rotation basic
AS5600
moving_handle
2handle
扇

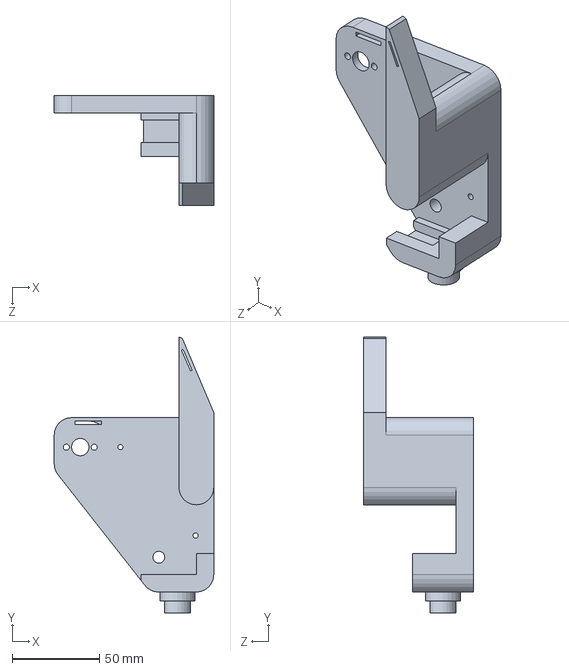
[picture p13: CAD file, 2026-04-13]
hardware/3basic.SLDPRT
91.5 x 158.2 x 63.0 mm

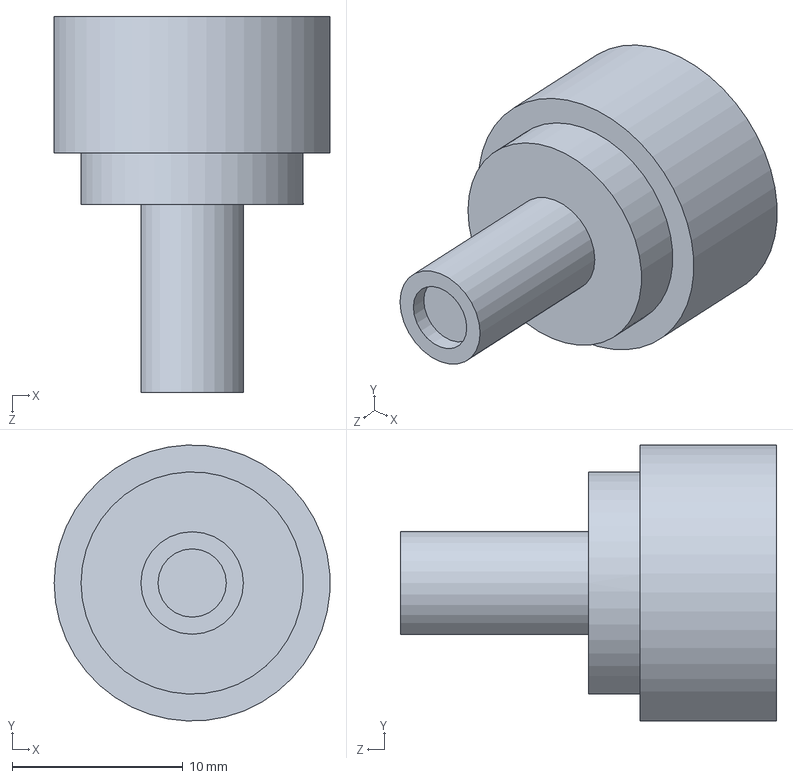
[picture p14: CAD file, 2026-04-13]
hardware/rotation basic.SLDPRT
16.1 x 16.1 x 22.0 mm

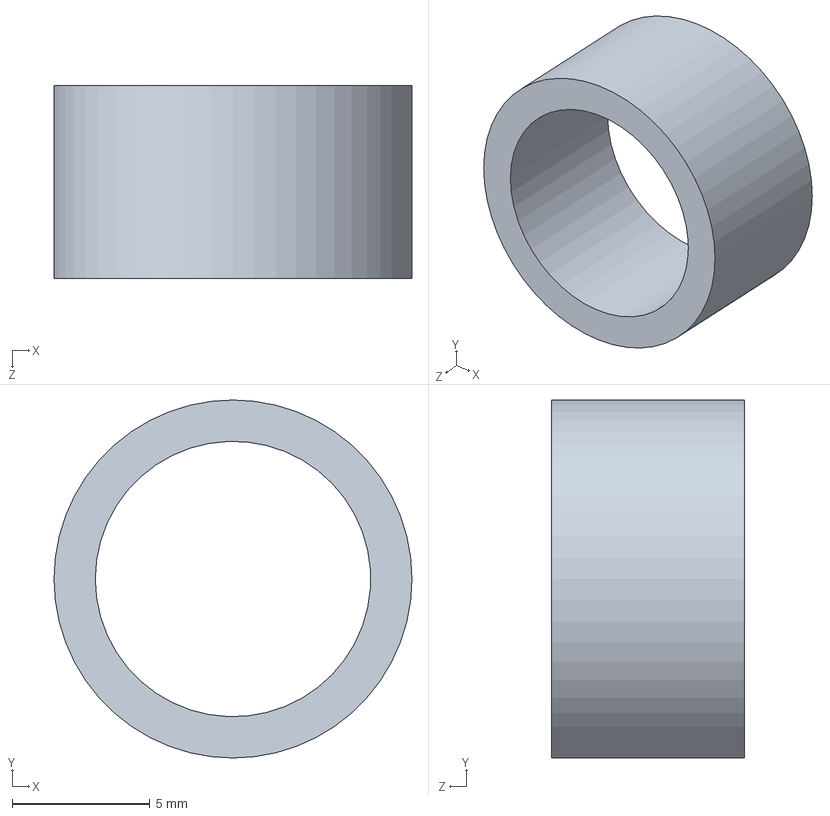
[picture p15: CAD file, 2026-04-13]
hardware/垫圈.SLDPRT
13.0 x 13.0 x 7.00 mm

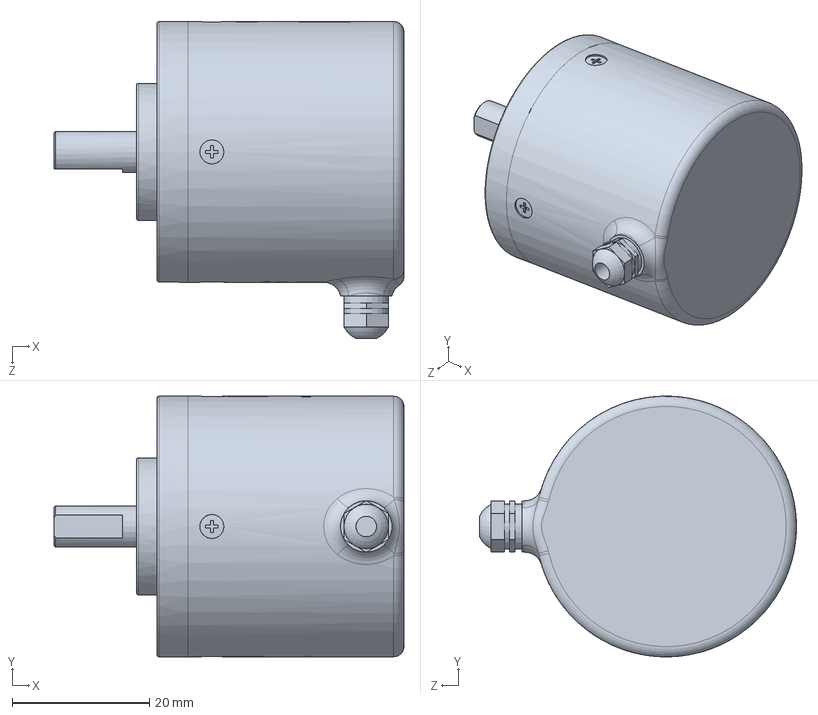
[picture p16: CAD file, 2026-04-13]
hardware/ESP3806-001系列增量式编码器_ESP3806-001G3600BZ15E.sldprt
51.0 x 38.0 x 46.2 mm

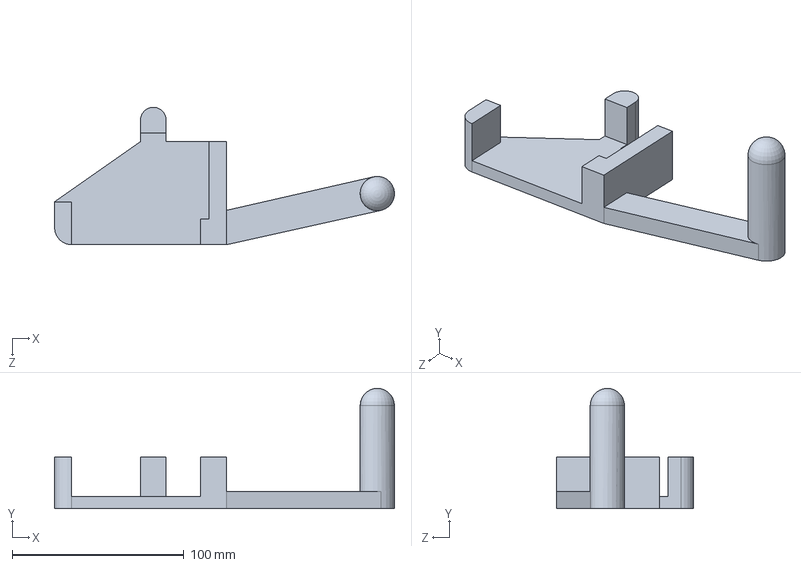
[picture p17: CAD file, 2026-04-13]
hardware/moving_handle.SLDPRT
197.8 x 70.0 x 80.0 mm

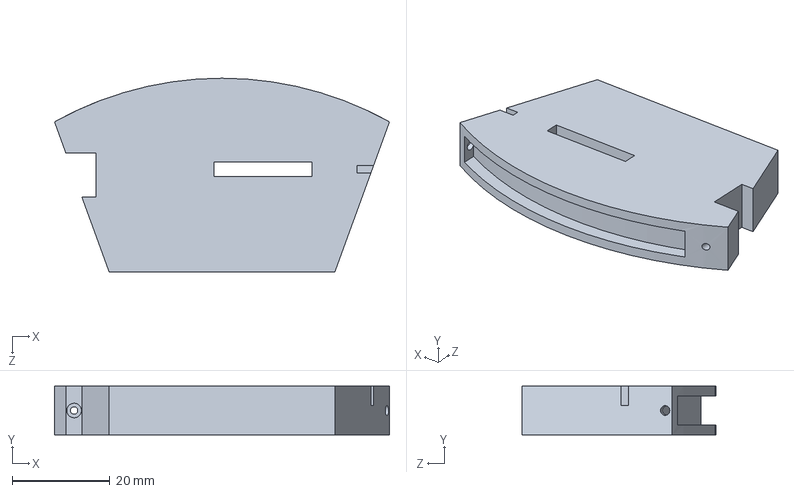
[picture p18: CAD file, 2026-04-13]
hardware/扇.SLDPRT
68.4 x 10.0 x 39.5 mm

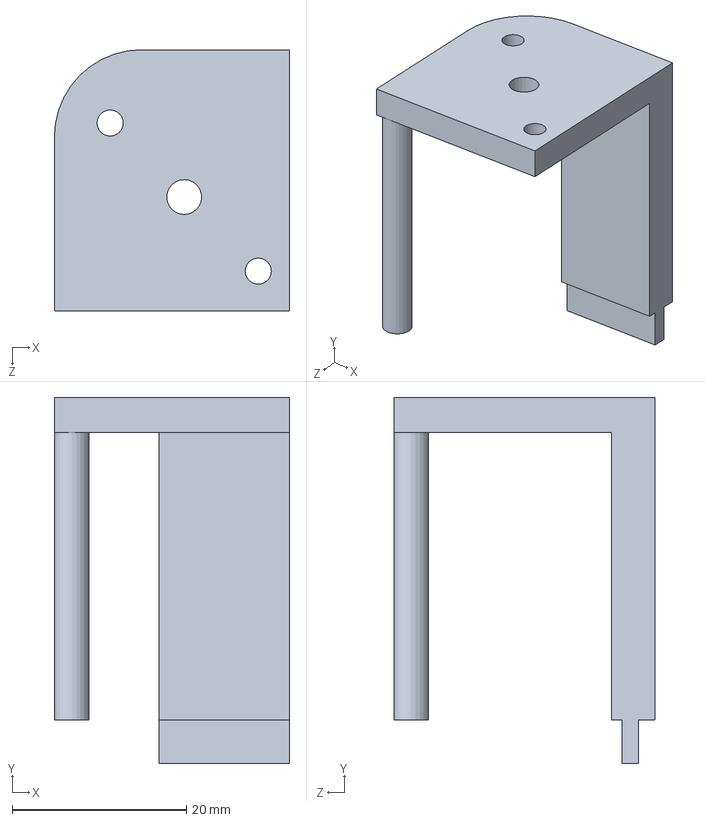
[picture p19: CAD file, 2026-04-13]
hardware/support.SLDPRT
27.0 x 42.0 x 30.0 mm

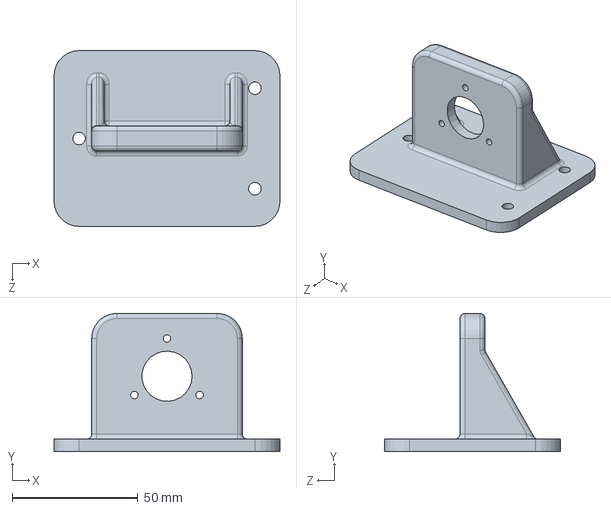
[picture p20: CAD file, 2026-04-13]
hardware/root.SLDPRT
90.0 x 55.0 x 70.0 mm

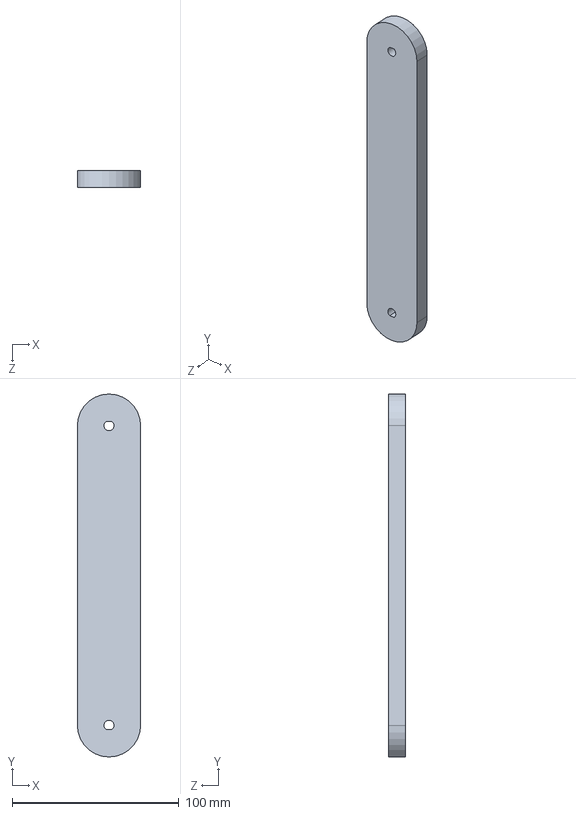
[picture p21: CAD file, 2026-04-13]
hardware/link2.SLDPRT
38.0 x 218.0 x 10.0 mm

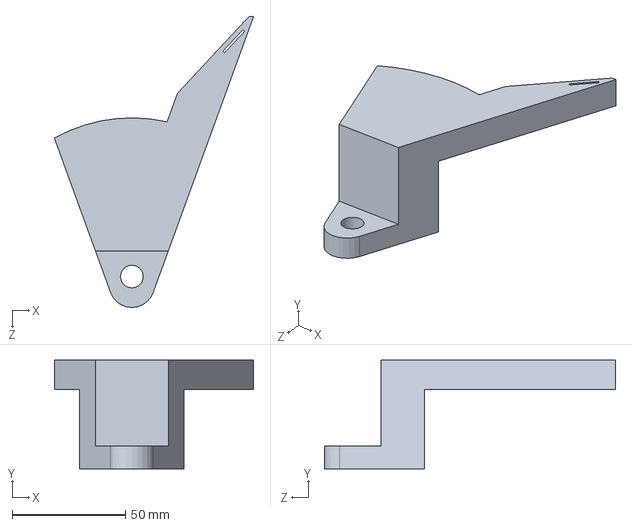
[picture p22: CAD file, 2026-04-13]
hardware/2handle.SLDPRT
87.9 x 48.0 x 128.4 mm

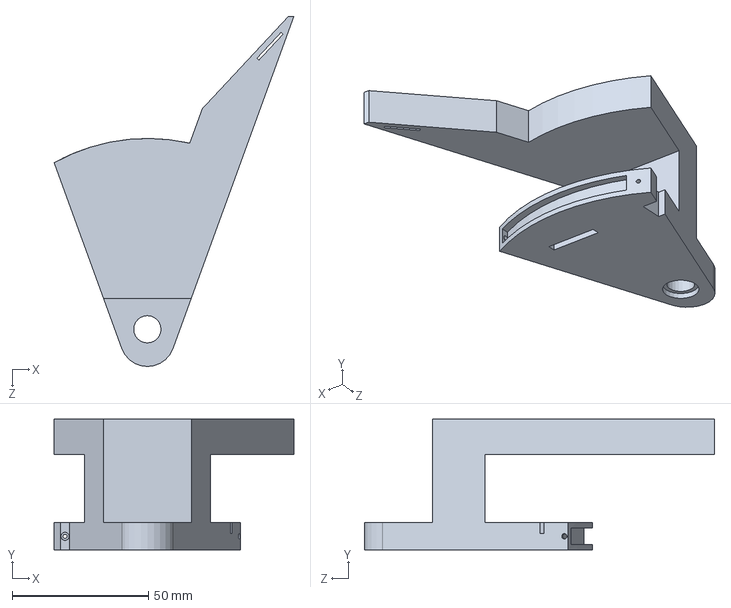
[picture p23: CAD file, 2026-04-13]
hardware/handle.SLDPRT
87.9 x 48.0 x 128.4 mm

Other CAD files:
hardware/link1.SLDPRT
hardware/AS5600.SLDPRT
hardware/RS-390-6V DC motor.SLDPRT
hardware/RS-380SH.SLDPRT
hardware/2basic.SLDPRT
hardware/6902ZZ 15×28×7_深沟球轴承.sldprt
hardware/ROTERY ENCODER.SLDPRT
hardware/basic.SLDPRT
hardware/final.SLDDRW
hardware/handle.SLDDRW
hardware/hapkit.SLDPRT
hardware/magnet.SLDPRT
hardware/motor_handle.SLDPRT
hardware/rotationlink.SLDPRT
hardware/装配体2.SLDDRW
hardware/装配体4.SLDDRW
hardware/轴套.SLDPRT

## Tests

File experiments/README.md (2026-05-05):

# Experiments and Iterations

## Overview

This section documents the testing, debugging, and iterative design process of the system.

Instead of only presenting final results, this section highlights key engineering challenges and how they were resolved.

---

## Contents

* **Encoder Drift Issue**

  * Problem: system could not return to zero position
  * Cause: loose encoder mounting
  * Solution: rigid fixation

* **AS5600 Alignment**

  * Problem: unstable angle readings
  * Cause: magnet misalignment
  * Solution: adjusted alignment and spacing

* **Gripper Design Iteration**

  * Problem: poor tactile perception
  * Cause: excessive thickness
  * Solution: tapered geometry

* **User Interaction Improvement**

  * Problem: pinch interaction unstable
  * Solution: added vertical handle

---

## Purpose

These experiments demonstrate the importance of mechanical design, sensor integration, and iterative refinement in building a reliable haptic system.

## 实验与迭代过程

### 概述

本部分记录了系统在开发过程中的测试、调试以及结构迭代过程。

相比仅展示最终结果，这里重点说明了在实际工程实现中遇到的关键问题、分析过程以及对应的解决方案，从而体现系统从原型到稳定运行的优化过程。

---

### 内容概览

#### 编码器漂移问题（Encoder Drift）

* **问题**：连杆在运动后无法准确回到初始零位，存在明显误差
* **原因**：编码器与轴连接不牢，存在相对滑动
* **解决方案**：通过螺丝对编码器进行刚性固定
* **结果**：零位稳定性显著提升，位置误差明显降低

---

#### AS5600 对齐问题（Sensor Alignment）

* **问题**：夹爪角度测量不稳定，读数存在波动
* **原因**：磁铁与传感器未正确对齐，间距不合适
* **解决方案**：调整磁铁轴向位置并控制间距在 1–3 mm
* **结果**：角度测量稳定性明显改善

---

#### 夹爪结构优化（Gripper Design Iteration）

* **问题**：夹爪前端过厚，用户手指无法完全闭合，影响触觉感知
* **原因**：初始设计未考虑人手操作空间
* **解决方案**：对夹爪前端进行斜向减薄设计（tapered geometry）
* **结果**：显著提升手指接触效果和尺寸感知能力

---

#### 人机交互改进（User Interaction）

* **问题**：初始采用双指捏合方式操作，控制不稳定
* **原因**：缺乏稳定的操作支撑结构
* **解决方案**：增加垂直握把（vertical handle）
* **结果**：操作更加稳定，力反馈感知更自然

---

### 工程意义

上述实验与改进过程表明：

* 机械结构设计对系统精度具有决定性影响
* 传感器安装与对齐直接影响测量可靠性
* 人机交互设计对触觉系统体验至关重要

通过不断迭代优化，系统最终实现了稳定运行与良好的交互效果。

---

### 说明

各具体问题的详细分析与实现过程可见对应文档：

* `encoder_drift.md`
* `as5600_alignment.md`
* `gripper_design_iteration.md`
* `user_interaction.md`

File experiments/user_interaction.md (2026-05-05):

# User Interaction Improvement

---

## Overview

During early testing, the interaction method between the user and the device was found to be unstable and unintuitive.

This led to a redesign of the interaction interface to improve usability and control.

---

## Problem Description

* The initial interaction relied on a pinch gesture using two fingers
* The grip was unstable during operation
* Users had difficulty maintaining consistent control
* Interaction felt unnatural, especially during continuous motion

This indicated that the original design lacked sufficient support for stable manipulation.

---

## Root Cause Analysis

The issue was primarily due to the lack of a stable interaction interface:

* No structural support for the user's hand
* The pinch-based interaction required continuous fine motor control
* Small disturbances led to large motion variations

---

## Design Modification

To improve usability, a vertical handle was introduced:

* A rigid vertical grip was added to the end-effector
* The handle allowed users to grasp the device more naturally
* Provided better support and control during operation

---

## Results

After introducing the handle:

* Interaction became significantly more stable
* Users could maintain better control over motion
* The overall user experience was improved

---

## Engineering Insight

This improvement highlights that:

> Human-machine interaction design is critical in haptic systems.

Providing a stable and ergonomic interface can greatly enhance system usability and performance.

---

---

# 人机交互优化

---

## 概述

在初期测试中发现，用户与设备之间的交互方式不稳定且不直观。

因此对交互方式进行了改进，以提升系统的可用性与控制稳定性。

---

## 问题描述

* 初始采用双指捏合方式进行操作
* 操作过程中稳定性较差
* 用户难以持续保持精确控制
* 在连续运动过程中交互不自然

说明原始设计缺乏稳定的操作支撑结构。

---

## 原因分析

问题主要在于交互方式本身：

* 缺乏手部支撑结构
* 捏合操作依赖精细控制
* 微小扰动会导致较大误差

---

## 改进方案

引入垂直握把（vertical handle）：

* 在末端增加刚性握把结构
* 允许用户以更自然的方式握持设备
* 提供稳定的操作支撑

---

## 改进效果

改进后：

* 操作稳定性显著提升
* 用户更容易控制设备运动
* 整体交互体验明显改善

---

## 工程启示

该改进表明：

> 人机交互设计在触觉系统中具有重要作用。

合理的结构设计可以显著提升系统的可用性与控制性能。

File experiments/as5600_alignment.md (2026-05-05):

# AS5600 Sensor Alignment Issue

---

## Overview

During testing, the gripper angle measurement using the AS5600 magnetic encoder was found to be unstable and inconsistent.

The readings exhibited noise and nonlinearity, which affected the accuracy of force feedback control.

---

## Problem Description

* The measured angle fluctuated even when the handle was stationary
* The output was not smooth during rotation
* Angle readings were inconsistent across repeated movements

This behavior indicated an issue with the sensing setup rather than the control logic.

---

## Root Cause Analysis

The issue was caused by improper alignment between the magnet and the AS5600 sensor:

* The magnet was not centered above the sensor
* The axial distance between the magnet and sensor was not optimal
* The magnetic field distribution was uneven

These factors resulted in inaccurate angle detection.

---

## Solution

To improve measurement accuracy, the following adjustments were made:

* Carefully aligned the magnet with the center of the AS5600 sensor
* Adjusted the axial distance to approximately 1–3 mm
* Ensured the magnet remained stable during rotation

---

## Results

After alignment:

* Angle readings became stable and smooth
* Measurement noise was significantly reduced
* Sensor output became consistent across repeated tests

---

## Engineering Insight

This issue highlights that:

> Magnetic sensors are highly sensitive to alignment and positioning.

Proper mechanical alignment is essential to ensure accurate and reliable measurements.

---

---

# AS5600 传感器对齐问题

---

## 概述

在系统调试过程中发现，使用 AS5600 磁编码器测量夹爪角度时，读数不稳定且存在明显波动。

该问题影响了力反馈控制的准确性。

---

## 问题描述

* 手柄静止时角度读数仍然波动
* 旋转过程中输出不平滑
* 多次测试结果不一致

该现象表明问题出现在传感器安装，而非控制算法。

---

## 原因分析

问题主要来源于磁铁与 AS5600 传感器之间的对齐不良：

* 磁铁未对准传感器中心
* 轴向距离不合适
* 磁场分布不均匀

导致角度测量误差和不稳定现象。

---

## 解决方案

针对该问题进行了如下调整：

* 将磁铁精确对准传感器中心位置
* 控制磁铁与传感器间距在 1–3 mm 范围内
* 确保磁铁在旋转过程中保持稳定

---

## 改进效果

调整后：

* 角度读数稳定且连续
* 噪声明显降低
* 多次测试结果一致性显著提升

---

## 工程启示

该问题说明：

> 磁编码器对安装精度高度敏感。

只有在正确对齐和合理间距下，才能获得稳定可靠的测量结果。

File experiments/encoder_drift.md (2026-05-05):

# Encoder Drift Issue

---

## Overview

During testing, the system exhibited significant position errors: after moving the linkage and returning it to the initial configuration, the measured position did not return to zero.

This issue directly affected the accuracy of position tracking and system reliability.

---

## Problem Description

* The linkage could not consistently return to its initial (zero) position
* The measured joint angles showed noticeable drift
* The error accumulated over repeated movements

This behavior indicated that the sensing system was not reliably capturing the actual joint motion.

---

## Root Cause Analysis

The issue was traced to the mechanical mounting of the incremental encoders.

* The encoder shaft was not rigidly fixed to the rotating joint
* Small relative motion occurred between the encoder and the shaft
* This introduced cumulative measurement error over time

As a result, the encoder readings no longer reflected the true joint angle.

---

## Solution

To eliminate the relative motion, the encoder mounting was improved:

* The encoder was rigidly fixed using screws
* The connection between the encoder and the rotating shaft was tightened
* Mechanical stability of the mounting structure was increased

---

## Results

After applying the fix:

* The linkage reliably returned to the zero position
* Measurement drift was eliminated
* Position tracking accuracy was significantly improved

---

## Engineering Insight

This issue highlights an important principle:

> Accurate sensing depends not only on sensor resolution, but also on mechanical integration quality.

Even high-resolution encoders can produce large errors if they are not properly mounted.

---

---

# 编码器漂移问题

---

## 概述

在系统调试过程中发现：当连杆运动后再返回初始位置时，测量结果无法回到零位，存在明显误差。

该问题直接影响了系统的位置跟踪精度与稳定性。

---

## 问题描述

* 连杆无法稳定回到初始零位
* 关节角度测量存在明显漂移
* 多次运动后误差逐渐累积

该现象表明传感系统未能准确反映真实的机械运动。

---

## 原因分析

问题来源于增量式编码器的机械安装方式：

* 编码器与旋转轴之间未实现刚性固定
* 存在微小相对滑动
* 随着运动累积产生测量误差

因此，编码器读数与实际角度逐渐偏离。

---

## 解决方案

针对该问题，进行了如下改进：

* 使用螺丝对编码器进行刚性固定
* 加强编码器与旋转轴之间的连接
* 提高整体安装结构的稳定性

---

## 改进效果

改进后：

* 连杆可以稳定回到零位
* 漂移问题消失
* 位置测量精度显著提升

---

## 工程启示

该问题说明：

> 传感精度不仅取决于传感器本身，还高度依赖机械安装质量。

即使是高精度编码器，如果安装不可靠，也会导致严重误差。

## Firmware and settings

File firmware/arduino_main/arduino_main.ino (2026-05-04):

#include <math.h>
#include <Wire.h>

#define AS5600_I2C_ADDRESS 0x36

// ---------------- Force-feedback motor driver ----------------
// Use a Hapkit-style interface: one PWM pin + one direction pin.
// Update these pins if your driver wiring is different.
const int MOTOR_PWM_PIN = 5;
const int MOTOR_DIR_PIN = 8;
const bool MOTOR_FEEDBACK_INVERT = true;
const bool DEBUG_FEEDBACK_SERIAL = true;
const float SERIAL_ANGLE_FILTER_ALPHA = 0.4;
const float SERIAL_ANGLE_HOLD_DEADBAND_DEG = 0.15;
const unsigned long SERIAL_STREAM_PERIOD_MS = 30;
const float GRIPPER_ANGLE_MAX_DEG = 360.0;

float targetWallAngleDeg = -1.0;
float targetWallStiffnessNPerM = 2000.0;
float targetWallForceGain = 1.0;
int targetWallContactMinPwm = 0;
unsigned long lastFeedbackPacketMillis = 0;
const unsigned long FEEDBACK_TIMEOUT_MS = 200;
const float VIRTUAL_WALL_DISABLED_DEG = -1.0;
const double HANDLE_RADIUS_M = 0.130;
const double MOTOR_PULLEY_RADIUS_M = 0.005;
const double SECTOR_PULLEY_RADIUS_M = 0.075;
const double DEFAULT_VIRTUAL_WALL_STIFFNESS_N_PER_M = 2000.0;
const double VIRTUAL_WALL_MAX_FORCE_N = 9999999999999999.0;
const double MOTOR_MAX_TORQUE_EST = 0.0183;
const double VIRTUAL_WALL_DUTY_EXPONENT = 1.20;
// "Virtual wall thickness": allow more penetration so squeezing further
// produces a larger force, but keep enough headroom to preserve softness
// differences between blocks.
const float VIRTUAL_WALL_MAX_PENETRATION_DEG = 30.0;  // was 20.0, then 45.0
const float VIRTUAL_WALL_MAX_DUTY = 0.92;             // was 0.90, then 0.98
const float VIRTUAL_WALL_CONTACT_ENTER_DEG = 2.2;
const float VIRTUAL_WALL_CONTACT_RELEASE_DEG = 0.5;
const float VIRTUAL_WALL_FORCE_FILTER_ALPHA = 0.10;
bool packetActive = false;
char packetBuffer[32];
uint8_t packetIndex = 0;
float previousWrappedGripperAngleDeg = 0.0;
float continuousGripperAngleDeg = 0.0;
bool gripperAngleInitialized = false;
bool suppressFeedbackWhileOpening = false;
bool lastMotorForward = true;
float filteredSerialAngleDeg = 0.0;
bool filteredSerialAngleInitialized = false;
bool virtualWallInContact = false;
double filteredWallForceN = 0.0;
unsigned long lastFeedbackDebugMillis = 0;

// ---------------- Encoder variables ----------------
long count1 = 0;
long count2 = 0;

uint8_t lastState1 = 0;
uint8_t lastState2 = 0;

unsigned long lastPrint = 0;

// quadrature lookup
int8_t quadTable[16] = {
   0, -1,  1,  0,
   1,  0,  0, -1,
  -1,  0,  0,  1,
   0,  1, -1,  0
};

// ---------------- Robot parameters ----------------
const float CPR = 2400.0;
const float L1  = 18.0;
const float L2  = 18.0;

const long offset1 = 240;
const long offset2 = 480;

// ---------------- AS5600 Calibration Parameters ----------------
// Step 1: Fully close the gripper, read the raw_angle from the Serial Monitor, and put it here.
float CLOSED_OFFSET = 157;

// Step 2: Fully open the gripper and measure how many sensor degrees the AS5600
// travels from fully closed to fully open. This value can be larger than 360.
// The reported gripper angle will then be scaled so:
//   fully closed -> 0 deg
//   fully open   -> 360 deg
float GRIPPER_OPEN_TRAVEL_SENSOR_DEG = 500.0;

// Step 3: If the reported angle decreases while opening, change this to -1.0.
float ANGLE_DIRECTION = 1.0; 

// -------------------------------------------------------------------------------------

void setVirtualWallTarget(float wallAngleDeg, float wallStiffnessNPerM, float wallForceGain, int wallContactMinPwm) {
  targetWallAngleDeg = wallAngleDeg;
  targetWallStiffnessNPerM = wallStiffnessNPerM;
  targetWallForceGain = wallForceGain;
  targetWallContactMinPwm = wallContactMinPwm;
  lastFeedbackPacketMillis = millis();
}

float shortestAngleDeltaDeg(float targetDeg, float referenceDeg) {
  float delta = targetDeg - referenceDeg;
  while (delta > 180.0) {
    delta -= 360.0;
  }
  while (delta < -180.0) {
    delta += 360.0;
  }
  return delta;
}

float wrapAngle360(float angleDeg) {
  while (angleDeg < 0.0) {
    angleDeg += 360.0;
  }
  while (angleDeg >= 360.0) {
    angleDeg -= 360.0;
  }
  return angleDeg;
}

void updateMotorFeedbackOutput(float gripperAngleDeg) {
  float wallAngleDeg = targetWallAngleDeg;
  float wallStiffnessNPerM = targetWallStiffnessNPerM;
  float wallForceGain = targetWallForceGain;
  int wallContactMinPwm = targetWallContactMinPwm;
  if (millis() - lastFeedbackPacketMillis > FEEDBACK_TIMEOUT_MS) {
    wallAngleDeg = VIRTUAL_WALL_DISABLED_DEG;
    wallStiffnessNPerM = 0.0;
    wallForceGain = 0.0;
    wallContactMinPwm = 0;
  }

  double desiredForce = 0.0;
  double penetrationDeg = 0.0;
  if (wallAngleDeg >= 0.0) {
    penetrationDeg = wallAngleDeg - gripperAngleDeg;

    // Use contact hysteresis so noise near the wall does not repeatedly switch
    // the contact state on and off at the block boundary.
    if (!virtualWallInContact && penetrationDeg > VIRTUAL_WALL_CONTACT_ENTER_DEG) {
      virtualWallInContact = true;
    } else if (virtualWallInContact && penetrationDeg < VIRTUAL_WALL_CONTACT_RELEASE_DEG) {
      virtualWallInContact = false;
    }

    if (virtualWallInContact) {
      double effectivePenDeg = penetrationDeg - VIRTUAL_WALL_CONTACT_RELEASE_DEG;
      if (effectivePenDeg < 0.0) {
        effectivePenDeg = 0.0;
      }
      if (effectivePenDeg > VIRTUAL_WALL_MAX_PENETRATION_DEG) {
        effectivePenDeg = VIRTUAL_WALL_MAX_PENETRATION_DEG;
      }
      double penetrationM = HANDLE_RADIUS_M * (effectivePenDeg * M_PI / 180.0);
      if (penetrationM < 0.0) {
        penetrationM = 0.0;
      }
      double activeWallStiffness = wallStiffnessNPerM > 0.0 ? wallStiffnessNPerM : DEFAULT_VIRTUAL_WALL_STIFFNESS_N_PER_M;
      double activeWallForceGain = wallForceGain > 0.0 ? wallForceGain : 1.0;
      desiredForce = activeWallStiffness * penetrationM * activeWallForceGain;
      if (desiredForce < -VIRTUAL_WALL_MAX_FORCE_N) desiredForce = -VIRTUAL_WALL_MAX_FORCE_N;
      if (desiredForce >  VIRTUAL_WALL_MAX_FORCE_N) desiredForce =  VIRTUAL_WALL_MAX_FORCE_N;
    }
  } else {
    virtualWallInContact = false;
  }

  filteredWallForceN += VIRTUAL_WALL_FORCE_FILTER_ALPHA * (desiredForce - filteredWallForceN);
  if (fabs(filteredWallForceN) < 0.02) {
    filteredWallForceN = 0.0;
  }
  double force = filteredWallForceN;

  const double J = (HANDLE_RADIUS_M * MOTOR_PULLEY_RADIUS_M) / SECTOR_PULLEY_RADIUS_M;
  double Tp = J * force;
  double normalizedTorque = fabs(Tp) / MOTOR_MAX_TORQUE_EST;
  if (normalizedTorque < 0.0) {
    normalizedTorque = 0.0;
  }
  double duty = pow(normalizedTorque, VIRTUAL_WALL_DUTY_EXPONENT);
  if (duty > VIRTUAL_WALL_MAX_DUTY) {
    duty = VIRTUAL_WALL_MAX_DUTY;
  }
  if (duty > 1.0) {
    duty = 1.0;
  } else if (duty < 0.0) {
    duty = 0.0;
  }
  if (virtualWallInContact && wallAngleDeg >= 0.0) {
    int minPwm = max(0, min(255, wallContactMinPwm));
    duty = max(duty, minPwm / 255.0);
  }

  int outputPwm = (int)(duty * 255.0);
  if (DEBUG_FEEDBACK_SERIAL && (millis() - lastFeedbackDebugMillis >= 200)) {
    lastFeedbackDebugMillis = millis();
    Serial.print("[FBDBG] wall_deg=");
    Serial.print(wallAngleDeg, 2);
    Serial.print(" k=");
    Serial.print(wallStiffnessNPerM, 1);
    Serial.print(" gain=");
    Serial.print(wallForceGain, 2);
    Serial.print(" min_pwm=");
    Serial.print(wallContactMinPwm);
    Serial.print(" contact=");
    Serial.print(virtualWallInContact ? 1 : 0);
    Serial.print(" pen_deg=");
    Serial.print(penetrationDeg, 2);
    Serial.print(" forceN=");
    Serial.print(force, 3);
    Serial.print(" duty=");
    Serial.print(duty, 3);
    Serial.print(" out=");
    Serial.println(outputPwm);
  }

  bool forward = (force > 0.0);
  if (MOTOR_FEEDBACK_INVERT) {
    forward = !forward;
  }
  lastMotorForward = forward;
  digitalWrite(MOTOR_DIR_PIN, forward ? HIGH : LOW);
  analogWrite(MOTOR_PWM_PIN, outputPwm);
}

void processIncomingFeedback() {
  while (Serial.available() > 0) {
    char c = (char)Serial.read();

    if (c == '<') {
      packetActive = true;
      packetIndex = 0;
      continue;
    }

    if (!packetActive) {
      continue;
    }

    if (c == '>') {
      packetBuffer[packetIndex] = '\0';
      float wallAngleDeg = VIRTUAL_WALL_DISABLED_DEG;
      float wallStiffnessNPerM = DEFAULT_VIRTUAL_WALL_STIFFNESS_N_PER_M;
      float wallForceGain = 1.0;
      int wallContactMinPwm = 0;
      char *firstComma = strchr(packetBuffer, ',');
      if (firstComma != nullptr) {
        *firstComma = '\0';
        wallAngleDeg = atof(packetBuffer);
        char *secondField = firstComma + 1;
        char *secondComma = strchr(secondField, ',');
        if (secondComma != nullptr) {
          *secondComma = '\0';
          wallStiffnessNPerM = atof(secondField);
          char *thirdField = secondComma + 1;
          char *thirdComma = strchr(thirdField, ',');
          if (thirdComma != nullptr) {
            *thirdComma = '\0';
            wallForceGain = atof(thirdField);
            wallContactMinPwm = atoi(thirdComma + 1);
          } else {
            wallForceGain = atof(thirdField);
          }
        } else {
          wallStiffnessNPerM = atof(secondField);
        }
      } else {
        wallAngleDeg = atof(packetBuffer);
      }
      setVirtualWallTarget(wallAngleDeg, wallStiffnessNPerM, wallForceGain, wallContactMinPwm);
      packetActive = false;
      packetIndex = 0;
      continue;
    }

    if (packetIndex < sizeof(packetBuffer) - 1) {
      packetBuffer[packetIndex++] = c;
    }
  }
}

void setup() {

  Serial.begin(115200);
  Wire.begin();
  if (MOTOR_PWM_PIN == 5 || MOTOR_PWM_PIN == 6) {
    // Pins 5/6 use Timer0 on AVR boards. Changing Timer0 also changes millis(),
    // which this sketch uses for serial pacing and feedback timeout logic.
    // Keep the default PWM frequency here to avoid unstable feedback behavior.
  } else {
    setPwmFrequency(MOTOR_PWM_PIN, 1);
  }

  pinMode(6, INPUT_PULLUP);   // Joint1 A
  pinMode(7, INPUT_PULLUP);   // Joint1 B

  pinMode(A0, INPUT_PULLUP);  // Joint2 A
  pinMode(A1, INPUT_PULLUP);  // Joint2 B

  pinMode(MOTOR_PWM_PIN, OUTPUT);
  pinMode(MOTOR_DIR_PIN, OUTPUT);
  setVirtualWallTarget(VIRTUAL_WALL_DISABLED_DEG, 0.0, 0.0, 0);
  updateMotorFeedbackOutput(0.0);

  // read initial state joint1
  uint8_t a1 = (PIND >> PD6) & 0x01;
  uint8_t b1 = (PIND >> PD7) & 0x01;
  lastState1 = (a1 << 1) | b1;

  // read initial state joint2
  uint8_t a2 = (PINC >> PC0) & 0x01;
  uint8_t b2 = (PINC >> PC1) & 0x01;
  lastState2 = (a2 << 1) | b2;
}

void loop() {
  processIncomingFeedback();
  if (filteredSerialAngleInitialized) {
    updateMotorFeedbackOutput(filteredSerialAngleDeg);
  } else {
    updateMotorFeedbackOutput(0.0);
  }
  

  // ---------- Joint1 ----------
  uint8_t a1 = (PIND >> PD6) & 0x01;
  uint8_t b1 = (PIND >> PD7) & 0x01;
  uint8_t currState1 = (a1 << 1) | b1;

  uint8_t index1 = (lastState1 << 2) | currState1;
  count1 += quadTable[index1];
  lastState1 = currState1;

  // ---------- Joint2 ----------
  uint8_t a2 = (PINC >> PC0) & 0x01;
  uint8_t b2 = (PINC >> PC1) & 0x01;
  uint8_t currState2 = (a2 << 1) | b2;

  uint8_t index2 = (lastState2 << 2) | currState2;
  count2 += quadTable[index2];
  lastState2 = currState2;

  // ---------- stream position and angle at a higher rate ----------
  if (millis() - lastPrint > SERIAL_STREAM_PERIOD_MS) {

    lastPrint = millis();

    // -------- convert to angles --------
    float theta1 = (count1 + offset1) * 2.0 * PI / CPR;
    float theta2 = -(count2 + offset2) * 2.0 * PI / CPR;

    // -------- Forward Kinematics --------
    float x = L1 * cos(theta1) + L2 * cos(theta1 + theta2) - 28.78;
    float z = L1 * sin(theta1) + L2 * sin(theta1 + theta2);

    x = -x;

    // -------- Read AS5600 --------
    Wire.beginTransmission(AS5600_I2C_ADDRESS);
    Wire.write(0x0E);
    Wire.endTransmission();
    Wire.requestFrom(AS5600_I2C_ADDRESS, 2);

    int angleValue = ((Wire.read() << 8) | Wire.read()) & 0x0FFF;
    float raw_angle = angleValue * 360.0 / 4096.0;

    // -------- Calibrate Angle (Continuous 0-360 logic) --------
    // 1. Subtract the zero offset
    float diff = raw_angle - CLOSED_OFFSET;
    
    // 2. Apply direction FIRST
    diff = diff * ANGLE_DIRECTION;
    
    // 3. Wrap into a strictly positive 0 to 360 range
    while (diff < 0.0) {
      diff += 360.0;
    }
    while (diff >= 360.0) {
      diff -= 360.0;
    }
    
    float wrapped_angle = diff;
    float final_angle = wrapped_angle;

    // 4. Track the calibrated angle continuously across the AS5600 wrap.
    // The internal angle may exceed 360 deg, but the exported angle is clamped
    // so the virtual gripper stays fully open instead of snapping back to 0.
    if (!gripperAngleInitialized) {
      previousWrappedGripperAngleDeg = wrapped_angle;
      continuousGripperAngleDeg = wrapped_angle;
      gripperAngleInitialized = true;
      suppressFeedbackWhileOpening = false;
    } else {
      float wrapped_delta = shortestAngleDeltaDeg(wrapped_angle, previousWrappedGripperAngleDeg);
      continuousGripperAngleDeg += wrapped_delta;
      if (continuousGripperAngleDeg < 0.0) {
        continuousGripperAngleDeg = 0.0;
      }
      previousWrappedGripperAngleDeg = wrapped_angle;
      suppressFeedbackWhileOpening = false;
    }
    float scaled_angle = continuousGripperAngleDeg * (GRIPPER_ANGLE_MAX_DEG / max(GRIPPER_OPEN_TRAVEL_SENSOR_DEG, 1.0f));
    final_angle = constrain(scaled_angle, 0.0, GRIPPER_ANGLE_MAX_DEG);

    if (!filteredSerialAngleInitialized) {
      filteredSerialAngleDeg = final_angle;
      filteredSerialAngleInitialized = true;
    } else {
      float delta = final_angle - filteredSerialAngleDeg;
      if (fabs(delta) > SERIAL_ANGLE_HOLD_DEADBAND_DEG) {
        filteredSerialAngleDeg += SERIAL_ANGLE_FILTER_ALPHA * delta;
      }
      filteredSerialAngleDeg = constrain(filteredSerialAngleDeg, 0.0, GRIPPER_ANGLE_MAX_DEG);
    }

    // ---------- Output ----------
    Serial.print(x);
    Serial.print(",");
    Serial.print(z);
    Serial.print(",");
    
    Serial.println(filteredSerialAngleDeg);

  }
}

// --------------------------------------------------------------
// Function to set PWM Freq -- based on Hapkit template
// --------------------------------------------------------------
void setPwmFrequency(int pin, int divisor) {
  byte mode;
  if (pin == 5 || pin == 6 || pin == 9 || pin == 10) {
    switch (divisor) {
      case 1: mode = 0x01; break;
      case 8: mode = 0x02; break;
      case 64: mode = 0x03; break;
      case 256: mode = 0x04; break;
      case 1024: mode = 0x05; break;
      default: return;
    }
    if (pin == 5 || pin == 6) {
      TCCR0B = TCCR0B & 0b11111000 | mode;
    } else {
      TCCR1B = TCCR1B & 0b11111000 | mode;
    }
  } else if (pin == 3 || pin == 11) {
    switch (divisor) {
      case 1: mode = 0x01; break;
      case 8: mode = 0x02; break;
      case 32: mode = 0x03; break;
      case 64: mode = 0x04; break;
      case 128: mode = 0x05; break;
      case 256: mode = 0x06; break;
      case 1024: mode = 0x07; break;
      default: return;
    }
    TCCR2B = TCCR2B & 0b11111000 | mode;
  }
}

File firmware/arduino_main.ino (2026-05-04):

long count1 = 0;
long count2 = 0;

uint8_t lastState1 = 0;
uint8_t lastState2 = 0;

unsigned long lastPrint = 0;

int8_t quadTable[16] = {
   0, -1,  1,  0,
   1,  0,  0, -1,
  -1,  0,  0,  1,
   0,  1, -1,  0
};

void setup() {
  Serial.begin(115200);

  pinMode(8, INPUT_PULLUP);   // Joint1 A
  pinMode(9, INPUT_PULLUP);   // Joint1 B
  pinMode(A0, INPUT_PULLUP);  // Joint2 A
  pinMode(A1, INPUT_PULLUP);  // Joint2 B

  // initial state
  uint8_t a1 = (PINB >> PB0) & 0x01;   // D8
  uint8_t b1 = (PINB >> PB1) & 0x01;   // D9
  lastState1 = (a1 << 1) | b1;

  uint8_t a2 = (PINC >> PC0) & 0x01;   // A0
  uint8_t b2 = (PINC >> PC1) & 0x01;   // A1
  lastState2 = (a2 << 1) | b2;
}

void loop() {
  // -------- Joint1 --------
  uint8_t a1 = (PINB >> PB0) & 0x01;   // D8
  uint8_t b1 = (PINB >> PB1) & 0x01;   // D9
  uint8_t currState1 = (a1 << 1) | b1;

  uint8_t index1 = (lastState1 << 2) | currState1;
  count1 += quadTable[index1];
  lastState1 = currState1;

  // -------- Joint2 --------
  uint8_t a2 = (PINC >> PC0) & 0x01;   // A0
  uint8_t b2 = (PINC >> PC1) & 0x01;   // A1
  uint8_t currState2 = (a2 << 1) | b2;

  uint8_t index2 = (lastState2 << 2) | currState2;
  count2 += quadTable[index2];
  lastState2 = currState2;

  // print slower
  if (millis() - lastPrint > 100) {
    lastPrint = millis();
    Serial.print("Joint1: ");
    Serial.print(count1);
    Serial.print("   Joint2: ");
    Serial.println(count2);
  }
}
